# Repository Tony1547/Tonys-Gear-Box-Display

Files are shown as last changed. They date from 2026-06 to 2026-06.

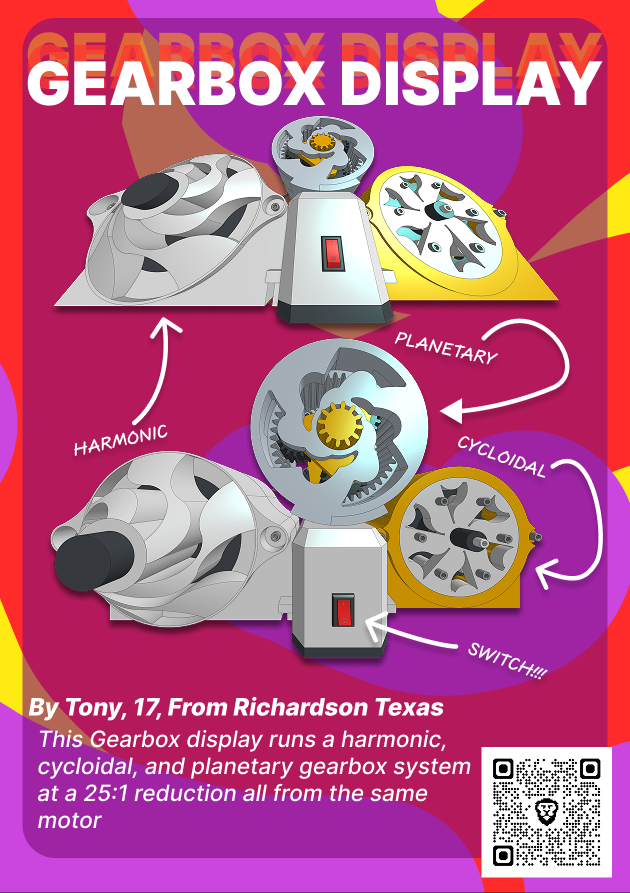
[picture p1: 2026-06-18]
Images/ZINE.png

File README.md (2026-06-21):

# Tonys-Gear-Box-Display
A harmonic, cycloidal, and planetary gearbox driven on one motor

<p align="center">
  
Hi! to whoever is reading this, I made this project becuase I wanted to have a better undersanding of common and uncommon ways to produce gear reduction, and every since finding out about cycloidal gearboxes I've been fascinated by the way they move and how to generate so much power without teeth. 

# CAD

- Onshape link: https://cad.onshape.com/documents/11a15da13425e31e4c0edb3a/w/1d53f7d84e63cf7b32fcd030/e/eb923a8e6ac061088489cd3c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

Harmonic Gearbox Assembly
(Inside of Harmonic GearBox Assembly)

Cycloidal Gear Box
(Inside of Cycloidal GearBox Assembly)

Stages 1 2
(Inside of Planetary GearBox Assembly)

Gearbox Display back view
(Full GearBox Assembly From the Back)

Gearbox Display Front View
(Full GearBox Assembly From the Front)

-------

Here I'd like to give thanks to GrabCad for hosting this model of the motor I'm Using for this project and this reddit thread that allowed me to skip doing all the math for the cycloidal gearbox

- https://www.reddit.com/r/Onshape/comments/1mckmf0/whats_the_easiest_way_to_make_a_cycloidal_drive/

- https://grabcad.com/library/jgb37-3530-geared-motor-1

-------

# Assembly

* Cycloidal

The Cycloidal Gear box has the most Hardwawre that is needed to assemble out of all three gear box types. 

Step one is to prepare and gather the needed materials for all three gear boxes, while doing so try and also make sure all 3d printed parts have had there M3 heated inserts heat pressed into them

Then you can start off by assembling the drive shaft and add the bearings

Afetr that Insert the bottom half of the output shaft and start stacking cycloidal disks (keep in mind that one of the three disks is different from the other two, that disk should be sandwiched in between the other two durring and after assembly)

When all disks are inserted you may now assemble the top half of the case and when everything fits into place, secure everything by using the screws. 

Make sure the drive shaft on the back of the Gearbox is properly installed and secure to the case

* Harmonic

Mount the wave generator to the drive Shaft

Then insert the drive shaft into the base, and make sure it is flush with the bottom

You can then insert the TPU gear and bend it around the wave generator

After that you can then take the top cover and secure the assembly with screws

* Planetary

Assemble the sun gears and planet gears by dropping in the planet gears into the triangles with gears at the top of them onto the rods they have on the bottom of them, and then clipping them in with the snap on clips 

After that you msy assemble each Stage by fitting the planet gears into the housing

on the front and back cover there are extrusions that allow pins to be places for mounting to the base, make sure the pins are installed before installing the front and back of the case

Then assemble the stages in reverse order from output to input allowing you to put on the driving planet gear and then the back cover of the case

* Full

Make sure you install the switch to the front cover of the base and the motor to the back, wire it so that the battery wire goes through the slot in the back into the battery tray, and leave right side up

You may now clip in the gear boxes, the planetary on top, the cycloidal to the right, and the harmonic to the left

Now place the pulleys on the driving shafts of each gearbox, after placing the pulleys  please install the belt

Now that everything is assembled the last thing to do is wire the battery and turn it on :)



(wiring diagram)

--------

# BOM

| Index | Vendor | Description | Quantity | Unit Price($) | Extended Price($) | Product Link |
|---|---|---|---|---|---|---|
| 1 | LCSC | hanxia HX KCD11-2P-R | 5 | $0.16 | $0.78 | https://www.lcsc.com/product-detail/C6917318.html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 |
| 2 | Amazon | M3 Heated Inserts | 100 | $0.05 | $4.99 | https://www.amazon.com/gp/product/B0FM45X5TD/ref=ewc_pr_img_3?smid=AIMQC13A5VC4X |
| 3 | EBAY | 160T GT2 Belt | 1 | $6.56 | $6.56 | https://www.ebay.com/itm/135168642404 |
| 4 | Ali Express | DC Motor | 1 | $10.37 | $10.37 | https://www.aliexpress.us/item/3256807873958725.html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 |
| 5 | Amazon | Screws | 321 | $0.03 | $8.99 | https://www.amazon.com/Washers-Machine-Assortment-Threaded-Furniture/dp/B0FGD91M1N/ref=sr_1_9?sr=8-9 |
| 6 | EBAY | Wire | 1 | $5.99 | $5.99 | https://www.ebay.com/itm/192206619575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 |
| 7 | Amazon | A23 Batteries | 2 | $1.45 | $2.89 | https://www.amazon.com/Energizer-Mercury-Alkaline-Batteries-Packaging/dp/B00004YK10/ref=sr_1_3?sr=8-3 |
| 8 | REV | Bearings | 4 | $3.25 | $13.00 | https://www.revrobotics.com/ION-Bearings/ |
| | | | | Total = | $53.57 | |

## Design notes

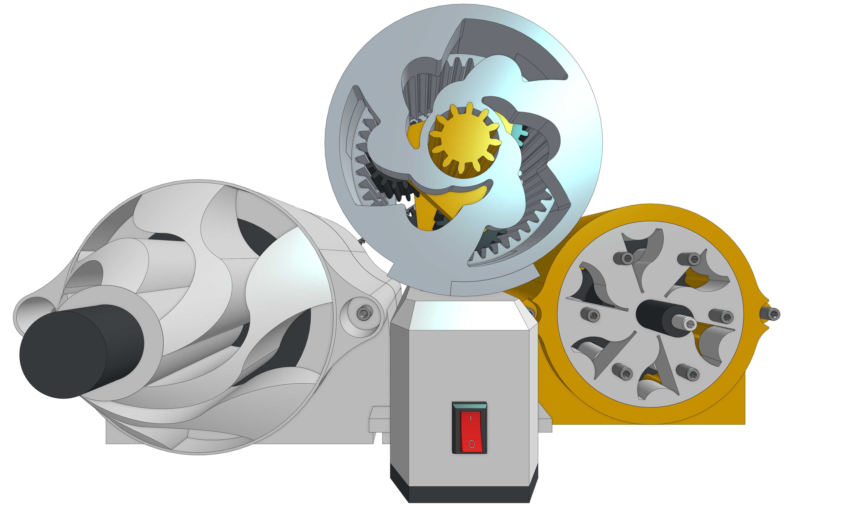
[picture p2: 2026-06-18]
Images/Gearbox Display image.png

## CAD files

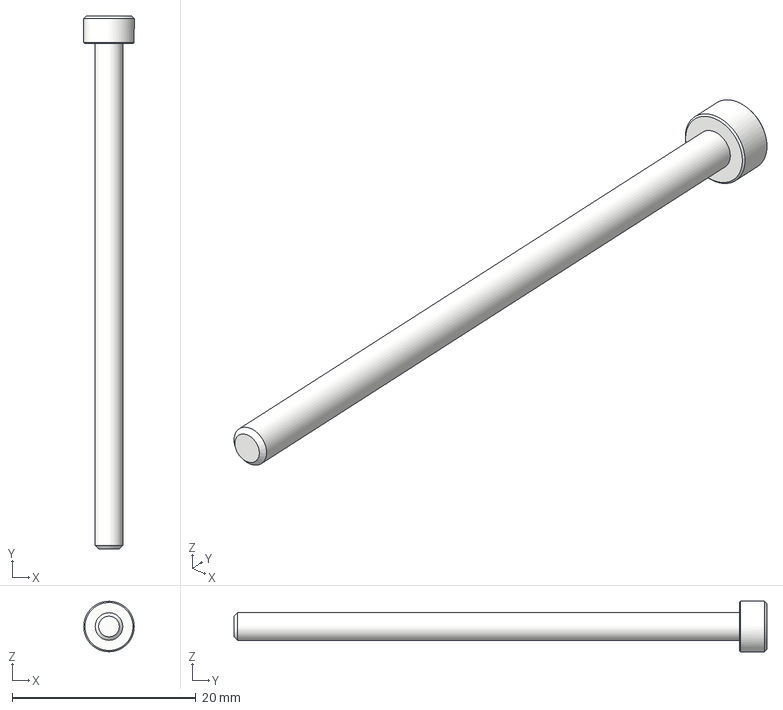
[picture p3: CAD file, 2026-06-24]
step files/hardware/Gearbox Display - M3x55 SHCS full thread.step
5.50 x 58.0 x 5.50 mm

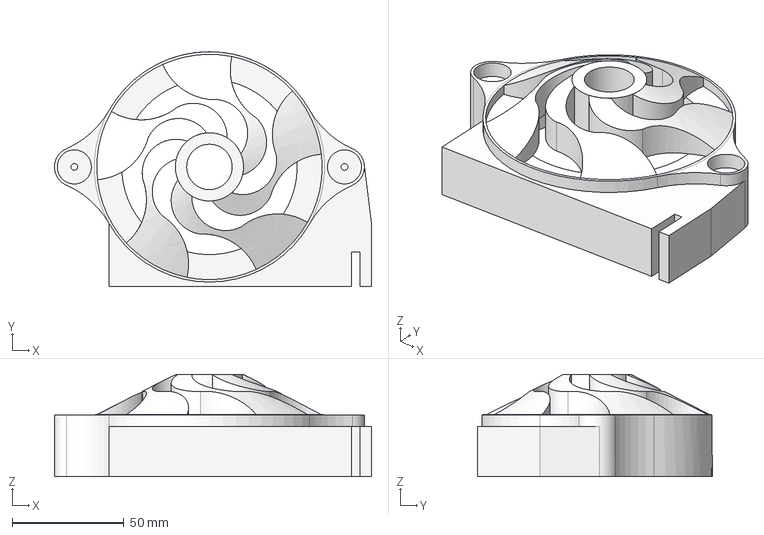
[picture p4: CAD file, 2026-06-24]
step files/base & bellt+pulley/Gearbox Display - Case Top Half.step
141.7 x 104.8 x 45.7 mm

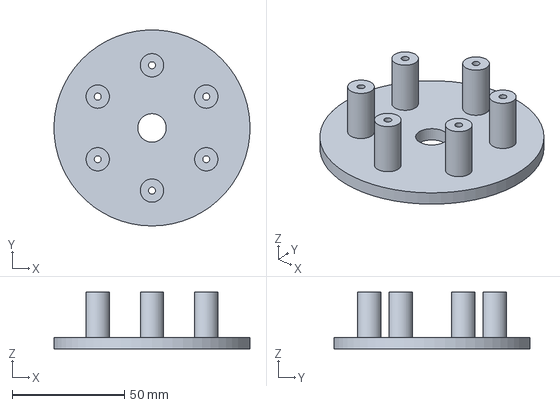
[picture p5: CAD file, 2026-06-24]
step files/cycloidal/Gearbox Display - Output Pins.step
87.4 x 87.4 x 25.4 mm

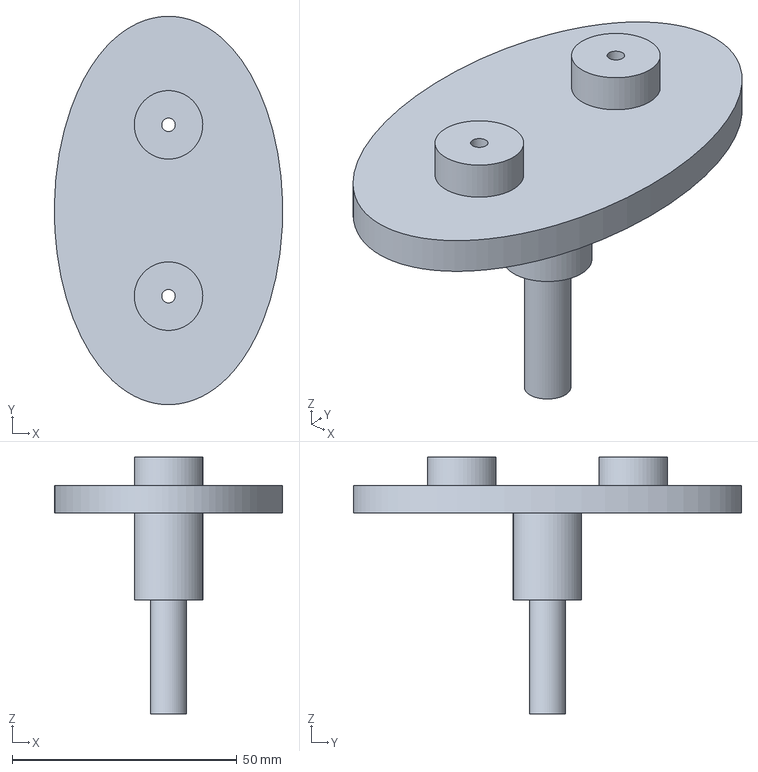
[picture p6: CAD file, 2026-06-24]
step files/harmonic/Gearbox Display - Input Shaft.step
50.8 x 86.4 x 57.1 mm

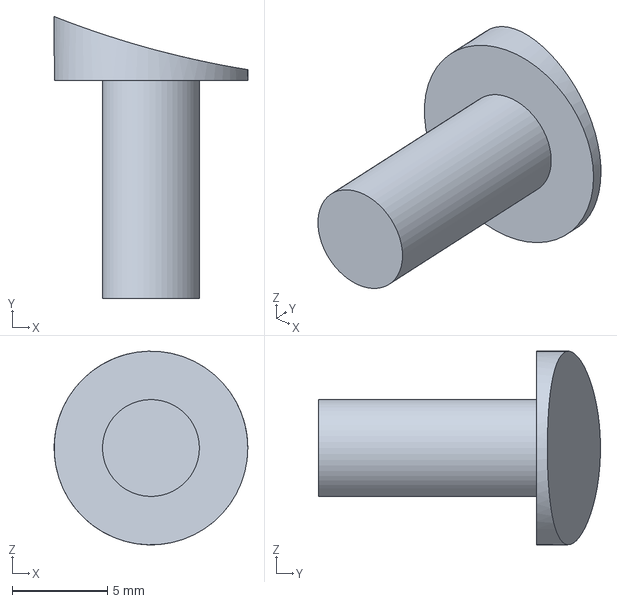
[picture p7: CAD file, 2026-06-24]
step files/planetary/Gearbox Display - Pin.step
10.2 x 14.8 x 10.2 mm

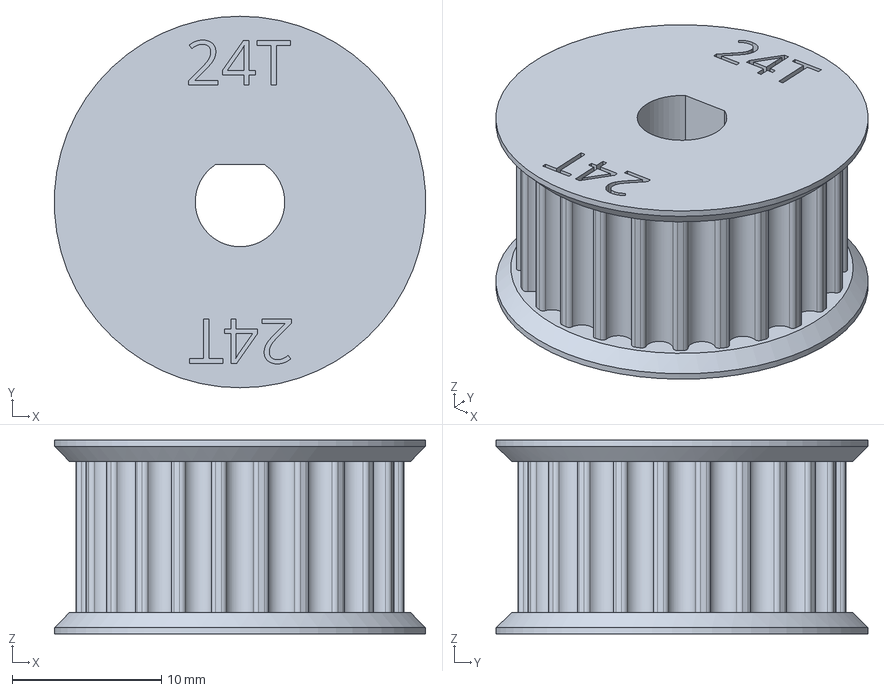
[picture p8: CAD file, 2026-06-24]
step files/base & bellt+pulley/Gearbox Display - 24T GT2 Pulley.step
24.9 x 24.9 x 13.0 mm

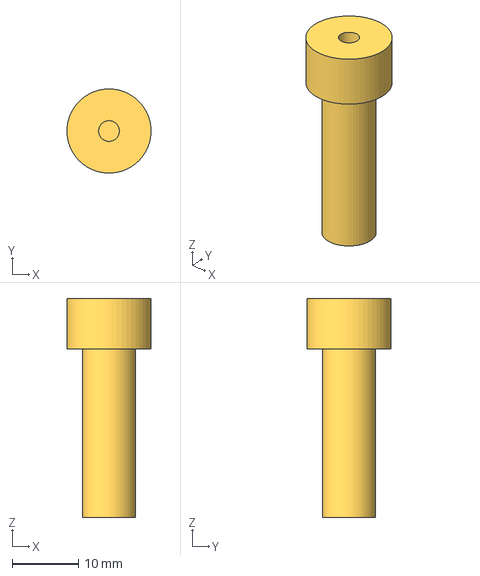
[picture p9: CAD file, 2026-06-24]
step files/cycloidal/Gearbox Display - Input Shaft (1).step
12.7 x 12.7 x 33.0 mm

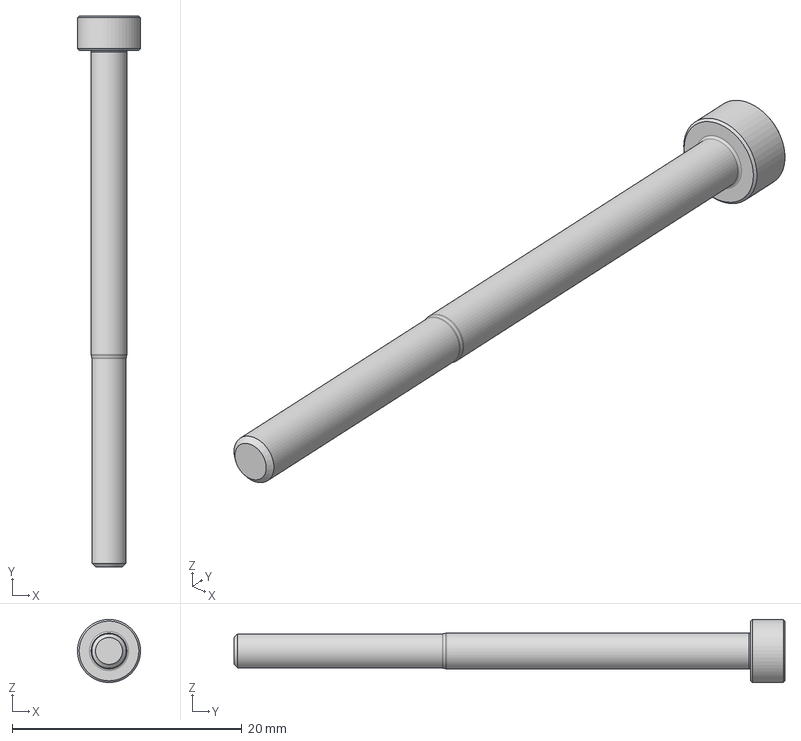
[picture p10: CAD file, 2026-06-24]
step files/hardware/Gearbox Display - M3x45 SHCS.step
5.50 x 48.0 x 5.49 mm

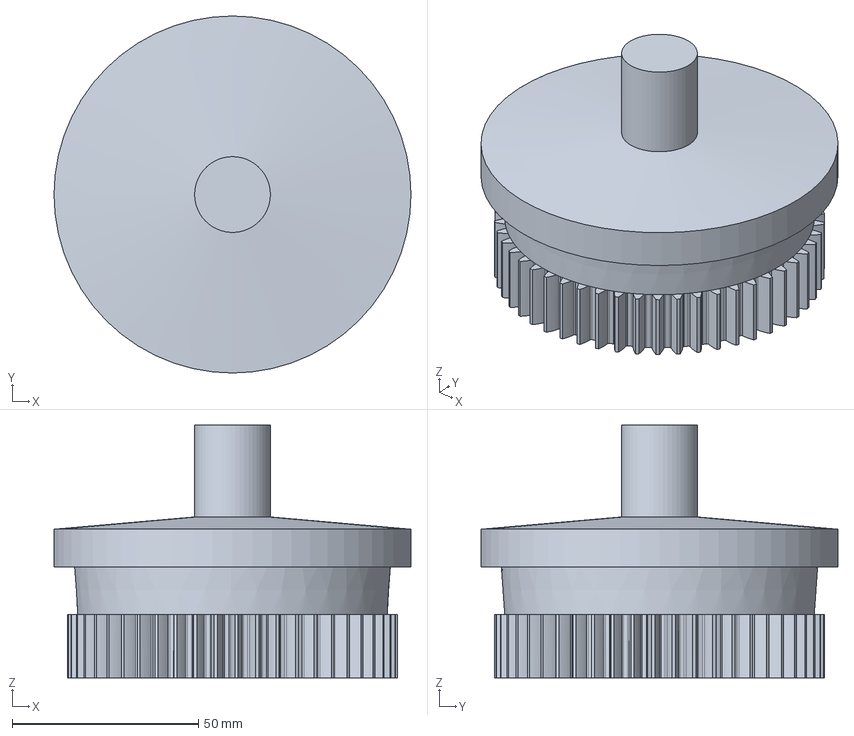
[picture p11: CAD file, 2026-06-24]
step files/harmonic/Gearbox Display - Output Gear.step
95.7 x 95.7 x 67.8 mm

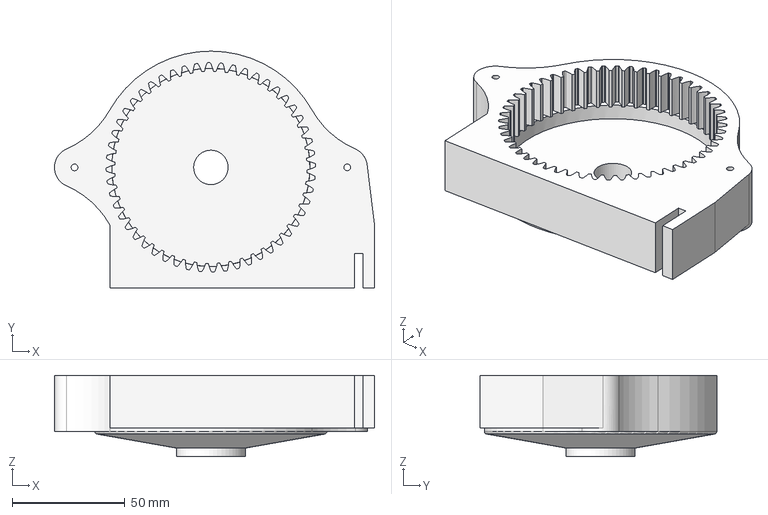
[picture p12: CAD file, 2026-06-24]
step files/base & bellt+pulley/Gearbox Display - Case Bottom Half.step
141.7 x 104.8 x 36.1 mm

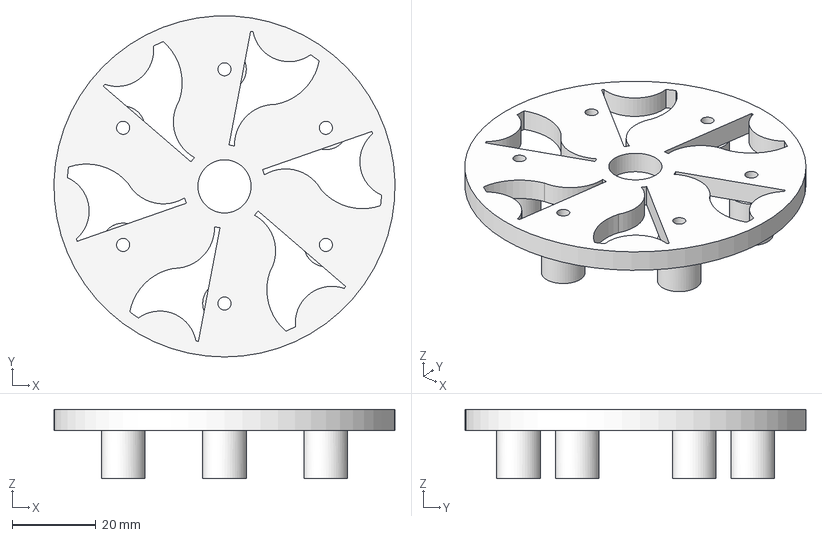
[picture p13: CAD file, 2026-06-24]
step files/cycloidal/Gearbox Display - Top Output Pins.step
81.4 x 81.3 x 16.5 mm

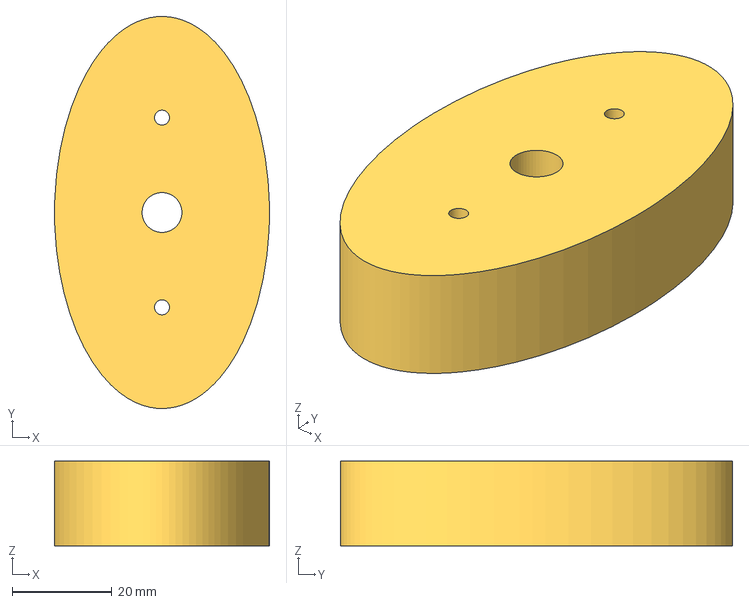
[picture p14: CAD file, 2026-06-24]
step files/harmonic/Gearbox Display - Wave Genertator.step
43.2 x 78.7 x 17.0 mm

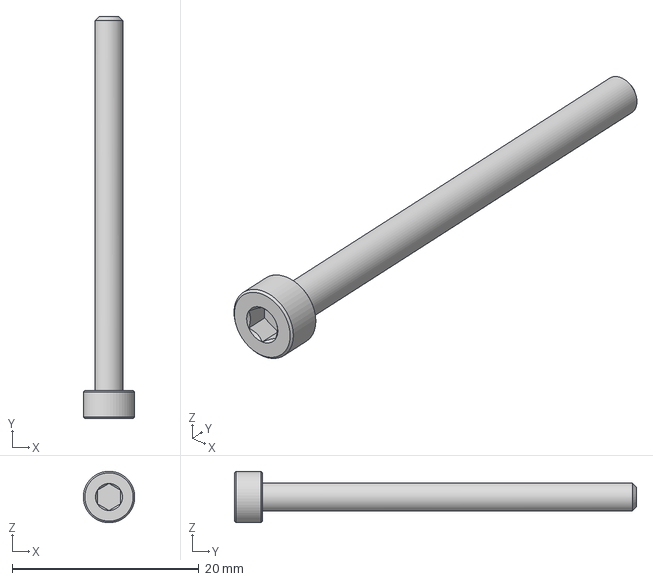
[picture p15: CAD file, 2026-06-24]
step files/hardware/Gearbox Display - M3x40 SHCS.step
5.49 x 43.0 x 5.50 mm

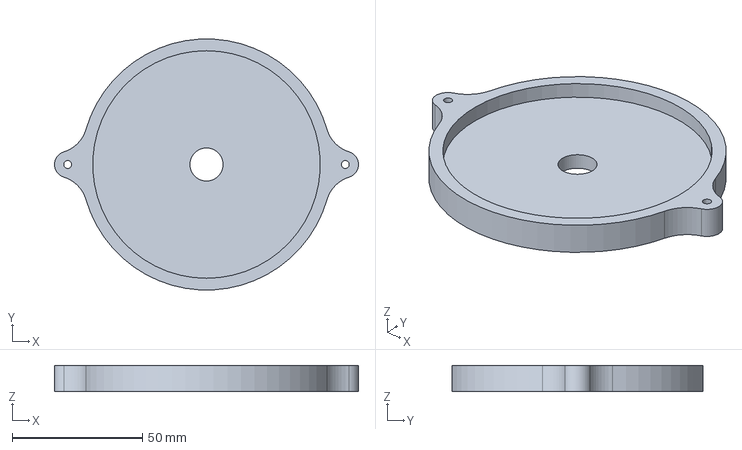
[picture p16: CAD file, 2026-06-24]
step files/base & bellt+pulley/Gearbox Display - Bottom of Case.step
116.8 x 96.4 x 10.2 mm

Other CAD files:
step files/cycloidal/Gearbox Display - Driving Shaft.step
step files/base & bellt+pulley/Gearbox Display - SW-TH_2P-L15.0-W10.5-P5.00_KCD11-2P-R.step
step files/cycloidal/Gearbox Display - Cycloidal Disk.step
step files/base & bellt+pulley/Gearbox Display - 160T GT2 Belt.step
step files/base & bellt+pulley/Gearbox Display - 24T GT2 Pulley (1).step
step files/base & bellt+pulley/Gearbox Display - 24T GT2 Pulley (2).step
step files/base & bellt+pulley/Gearbox Display - 24T GT2 Pulley (3).step
step files/base & bellt+pulley/Gearbox Display - Bottom of Base.step
step files/base & bellt+pulley/Gearbox Display - JGB37-3530 12V DC Motor.step
step files/base & bellt+pulley/Gearbox Display - SW-TH_2P-L15.0-W10.5-P5.00_KCD11-2P-R (1).step
step files/base & bellt+pulley/Gearbox Display - Top of Base.step
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

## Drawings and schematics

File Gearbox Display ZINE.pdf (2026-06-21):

# GEARBOX DISPLAY

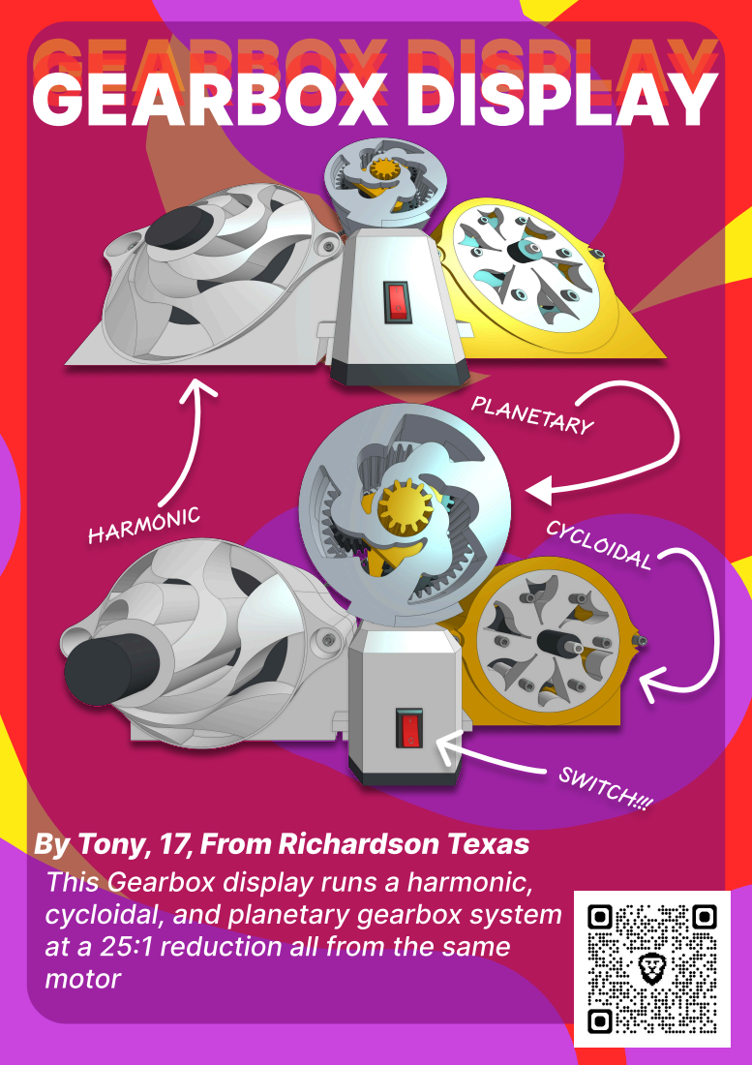
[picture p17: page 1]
HARMONIC; PLANETARY; CYCLOIDAL; SWITCH!!!

By Tony, 17, From Richardson Texas
This Gearbox display runs a harmonic,
cycloidal, and planetary gearbox system
at a 25:1 reduction all from the same
motor

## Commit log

2026-06-18 FIles and organize
    [Gearbox Display - 1-2- Rounded Hex (13.75mm) ID Bearing (1.125- OD, 0.313- WD, Shielded, Flanged).stl, Gearbox Display - 24T GT2 Pulley (1).stl, Gearbox Displa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]
2026-06-18 More organize
    [Gearbox Display - 24T GT2 Pulley (1).stl, Gearbox Display - 24T GT2 Pulley (2).stl, Gearbox Display - 24T GT2 Pulley (3).stl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]
2026-06-18 CAD fixes
    [Cycloidal Gear Box - Bottom of Case.stl, Gearbox Display - Bottom of Case.stl]
2026-06-21 add zine pdf and rename assembly
2026-06-21 update name
    [Cycloidal Gear Box - Bottom of Case.stl, Gearbox Display - 1-2- Rounded Hex (13.75mm) ID Bearing (1.125- OD, 0.313- WD, Shielded, Flanged).stl, Gearbox Display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]
2026-06-24 stl to step fix
    [Cycloidal Gear Box - Bottom of Case.stl, Gearbox Display - 1-2- Rounded Hex (13.75mm) ID Bearing (1.125- OD, 0.313- WD, Shielded, Flanged) (1).step, Gearbox Di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]
2026-06-24 rename folder
    [Gearbox Display - 1-2- Rounded Hex (13.75mm) ID Bearing (1.125- OD, 0.313- WD, Shielded, Flanged) (1).step, Gearbox Display - 1-2- Rounded Hex (13.75mm) ID Bea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]
2026-06-24 bom rename
    [GEARBOX DISPLAY BOM.csv]
